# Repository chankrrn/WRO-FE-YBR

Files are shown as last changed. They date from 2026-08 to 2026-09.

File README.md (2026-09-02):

# *YBR-SUNFLOWER 🌻*

<div align="center">

## WRO 2026 Future Engineers

### Official Engineering Documentation

**Yothinburana School — Science–Mathematics English Program**  
**Thailand**

<br>

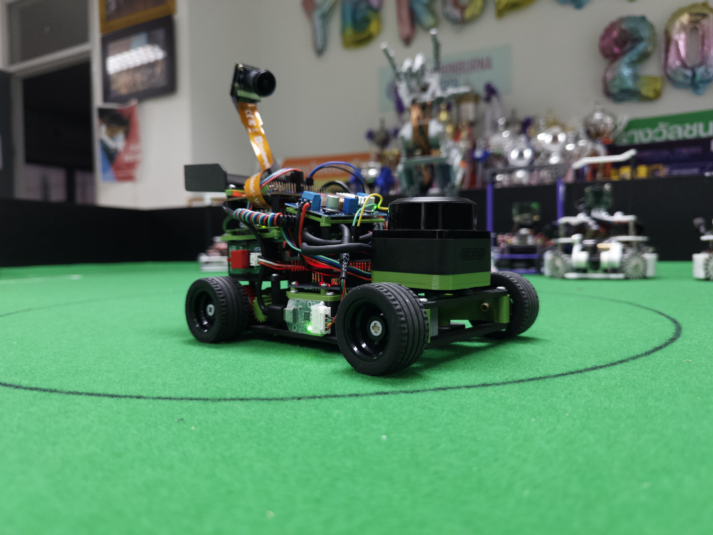
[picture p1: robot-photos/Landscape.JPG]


<br><br>

**Autonomous Self-Driving Vehicle · Mechanical Engineering · Electrical & Sensor Architecture · Localization · Computer Vision · Autonomous Navigation**

</div>

---

## Documentation Quick Links

| Documentation | Purpose |
|---|---|
| [Mechanical Design](mech/mech_README.md) | Chassis, drivetrain, steering, CAD, materials, mechanical calculations, trade-offs and iterations |
| [Electrical & Sensor System](elec/elec_README.md) | Power architecture, controllers, sensors, wiring, calibration, interfaces and reliability |
| [Software Architecture](software/software_README.md) | Localization, path planning, Pure Pursuit, computer vision, sensor fusion, obstacle strategy and parking |
| [Build & Reproduction Guide](BUILD.md) | Complete assembly, wiring, software setup, upload, verification and troubleshooting procedure |
| [Source Code](src/) | Raspberry Pi and Arduino competition software |
| [Schematics](schemes/) | Electrical schematic and physical wiring diagrams |
| [Mechanical Models](mech/models/) | CAD and 3D-printable mechanical parts |
| [Robot Photos](robot-photos/) | Final robot photographs |
| [Videos](video/) | Test and competition demonstration videos |

---

# Contents

1. [Our Team](#1-our-team)
2. [Project Overview](#2-project-overview)
3. [Final Robot](#3-final-robot)
4. [Engineering Development Process](#4-engineering-development-process)
5. [System Architecture](#5-system-architecture)
6. [Mobility and Mechanical Engineering](#6-mobility-and-mechanical-engineering)
7. [Power and Sensor Architecture](#7-power-and-sensor-architecture)
8. [Software Architecture and Autonomous Strategy](#8-software-architecture-and-autonomous-strategy)
9. [Systems Thinking and Major Engineering Decisions](#9-systems-thinking-and-major-engineering-decisions)
10. [Testing, Validation and Failure Analysis](#10-testing-validation-and-failure-analysis)
11. [Build and Reproducibility](#11-build-and-reproducibility)
12. [Repository Structure](#12-repository-structure)
13. [Version History and Development Milestones](#13-version-history-and-development-milestones)
14. [WRO Engineering Documentation Map](#14-wro-engineering-documentation-map)
15. [References and Related Documentation](#15-references-and-related-documentation)

---

# 1. Our Team

## 1.1 Team Members

<div align="center">
  
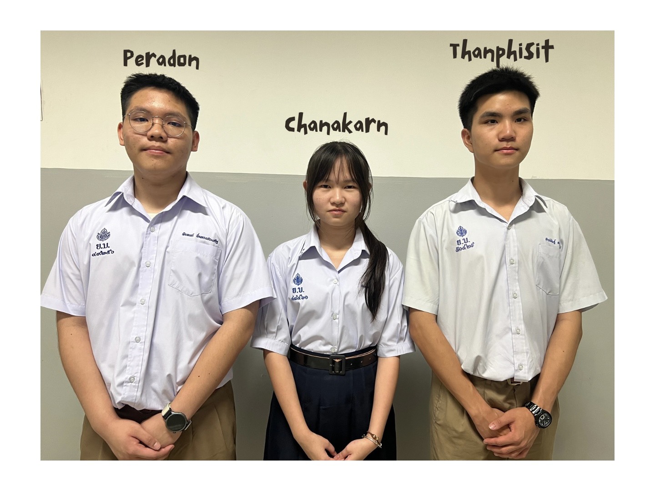
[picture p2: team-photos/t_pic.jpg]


</div>

<br>

We are **YBR-SUNFLOWER**, representing Yothinburana School, Thailand.

| Member | Primary Responsibility | Supporting Responsibilities |
|---|---|---|
| **Peradon Nimsongprasert** | Robot construction and software development | Robot testing, debugging, and performance optimization |
| **Chanakarn Yimsakul** | Documentation and technical writing | Organizing project information, recording development progress, and supporting software development |
| **Thanphisit Sakulvitulthai** | Hardware development and electrical systems | Supporting documentation, hardware testing, and robot assembly |

**Mentor:** Mr. Punnapon Tanasnitikul

---

## 1.2 How We Work as a Team

Our development process integrates mechanical, electrical, and software work throughout the development. A mechanical change can affect steering behavior, while a sensor-placement change can affect localization. Similarly, a power-system change can affect computing reliability, and a software change can reveal mechanical limitations that were not clear during static testing. 

Therefore, subsystem decisions are developed and tested as part of the complete robot rather than independently until the final stage.

Our team divides the work based on each member’s main area of responsibility. Peradon focuses on building the robot and developing the code, Chanakarn is mainly responsible for documentation, and Thanphisit focuses on hardware development while also supporting the documentation. We regularly discuss changes and test the robot together to make sure that mechanical, hardware, and software improvements work well as a complete system.

---

# 2. Project Overview

## 2.1 About YBR-SUNFLOWER

**YBR-SUNFLOWER** is an autonomous self-driving vehicle developed for the **WRO 2026 Future Engineers** competition by a three-member student team from the Science–Mathematics English Program at Yothinburana School, Thailand.

The vehicle combines mechanical design, embedded control, electrical engineering, computer vision, LiDAR localization, orientation sensing and autonomous navigation into one integrated system.

The robot was not developed as a set of independent components. Mechanical, electrical and software decisions were repeatedly changed together as testing revealed limitations in earlier designs.

Our main engineering priorities are:

1. **Precision**
2. **Stability**
3. **Reliability**
4. **Repeatability**
5. **Reproducibility**

We deliberately prioritize predictable autonomous behavior over maximum theoretical speed.

---

## 2.2 Competition Challenge

The WRO Future Engineers competition requires the vehicle to operate fully autonomously on a field whose configuration is not completely known before the round begins.

The competition contains two major driving challenges.

### Open Challenge

The vehicle must autonomously complete three laps while responding to the randomized track configuration and driving direction.

**Performance Video:** [Open Challenge Performance Video](https://youtu.be/PEgQhpqOltk?si=T_KtnxKnviS_btky)

### Obstacle Challenge

The vehicle must:

1. complete three autonomous laps,
2. detect red and green traffic pillars,
3. pass each traffic pillar on the correct side,
4. adapt to randomized obstacle positions,
5. identify the parking situation,
6. and perform the required parallel-parking maneuver.

The starting position, driving direction and field configuration may change between rounds.

For this reason, our final software does not depend on one fixed prerecorded path from one fixed starting point.

**Performance Video:** [Obstacle Challenge Performance Video](https://youtu.be/pB4Do4b9KFg?si=JDbvOoWnJ5U209h_)

> **All the videos including additional testing videos can be found in:** [`video/`](https://github.com/chankrrn/WRO-FE-YBR-SUNFLOWER/tree/17945a607ef416fb5d24ce5c4f617b4a04b09428/video)

---

## 2.3 Competition Constraints That Influenced Our Design

| Constraint | Engineering Response |
|---|---|
| Fully autonomous operation | All sensing, localization, decision-making and actuator control run onboard |
| Randomized field configuration | LiDAR-based localization and field-coordinate navigation |
| Randomized driving direction | Path direction can be selected during initialization |
| Red / green traffic pillars | Camera-based color recognition and obstacle mapping |
| Parallel parking requirement | Distance-based movement and dedicated parking sequence |
| Maximum robot dimensions | Compact stacked mechanical and electrical layout |
| Three-minute run limit | Efficient initialization and autonomous execution |
| One main power switch and one competition start button | Separate SPST main switch and ZX-Switch01 start control |
| Limited onboard power | Single 3S LiPo with separated power branches |
| Limited physical space | Layered chassis and compact sensor placement |

---

## 2.4 Engineering Design Philosophy

A major engineering decision throughout this project was:

> **Precision, stability and repeatability are more important to our robot than maximum speed.**

This principle influenced the complete system. Mechanically, it affected motor selection, drivetrain reduction, Ackermann-style steering, bearing support and chassis rigidity. Electrically, it influenced sensor placement and the decision to separate the Raspberry Pi power path from actuator-related loads.

The same philosophy also influenced software development. Localization, path tracking, steering control and parameter tuning were designed around predictable behavior rather than aggressive speed. The final result is a vehicle intended to perform the same maneuver consistently instead of being optimized only for its fastest possible run.

---

# 3. Final Robot

## 3.1 Robot at a Glance

| Category | Final Configuration |
|---|---|
| Robot type | Four-wheel automotive-style autonomous vehicle |
| Main computer | Raspberry Pi 5 |
| Low-level controller | Arduino UNO R4 Minima |
| Drive motor | CHP-20GP-180 brushed DC geared motor with quadrature encoder |
| Internal motor gearbox | 19:1 reduction |
| External drivetrain | 16-tooth motor gear → 28-tooth differential gear |
| Steering | Servo-driven Ackermann-style steering |
| Steering servo | GEEKSERVO 2 kg 360° servo |
| Distance sensing | RPLiDAR C1 |
| Vision | Raspberry Pi Night Vision Camera |
| Orientation sensing | Gravity BNO055 IMU |
| Drive feedback | Dual-phase motor encoder |
| Pi I/O interface | DFR0566 IO Expansion HAT |
| Motor driver | L298P Motor Shield |
| Main battery | 11.1 V 3S LiPo, 1100 mAh |
| Power architecture | Separate computing and motor/control branches |
| Final dimensions | Approximately **230 × 140 × 130 mm** |
| Final weight without LiPo battery | 768 grams |
| Final weight with LiPo battery | 854 grams |
| Final physical version | Version 3 |

---

## 3.2 Final Robot — Six-View Documentation

The following photographs document the final competition robot from all required directions.

| Front View | Right View | Rear View |
|---|---|---|
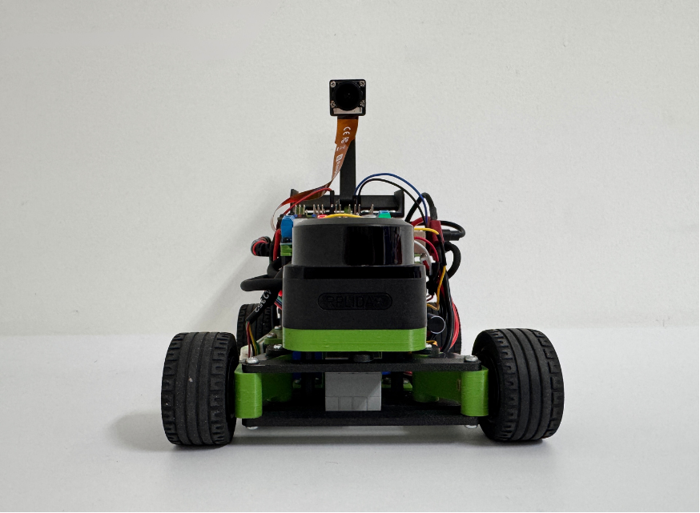
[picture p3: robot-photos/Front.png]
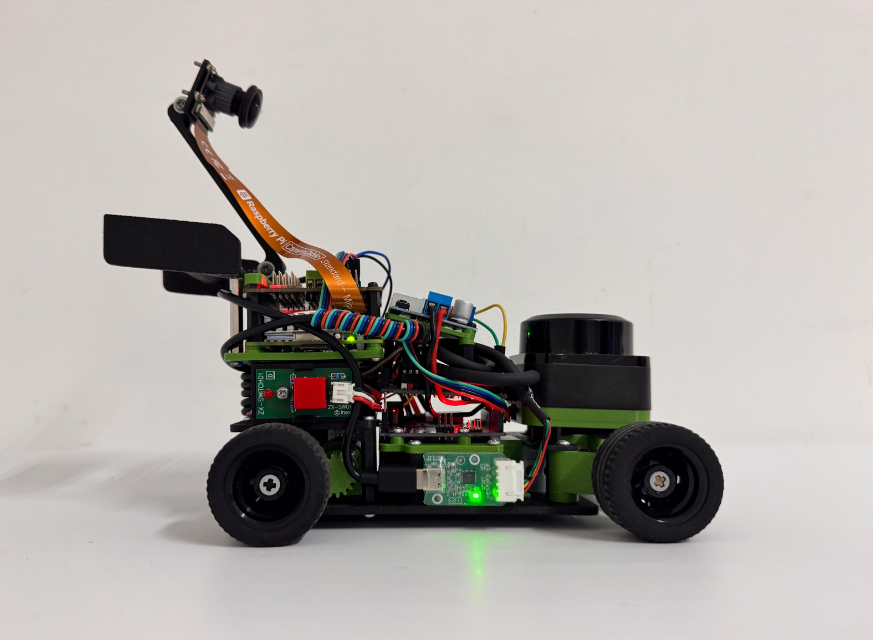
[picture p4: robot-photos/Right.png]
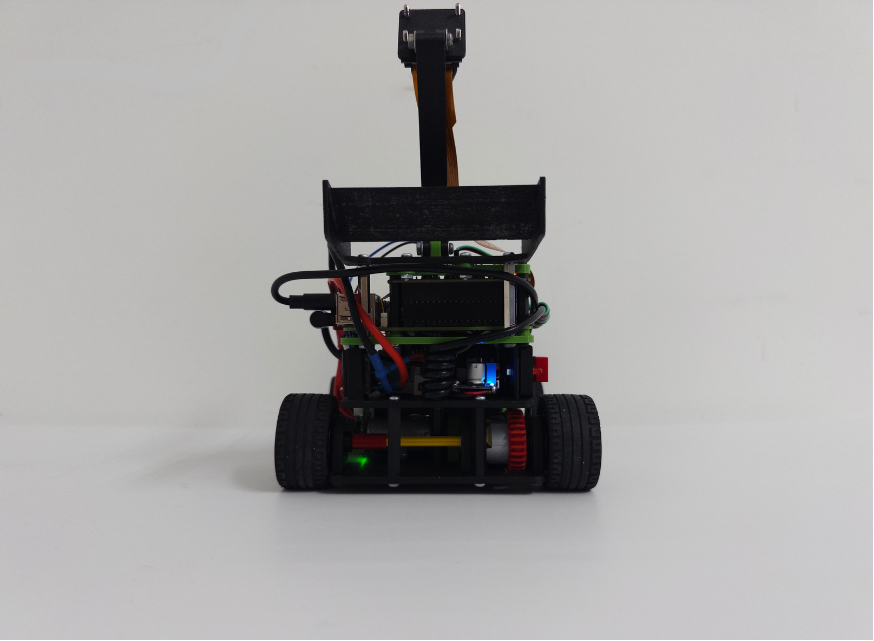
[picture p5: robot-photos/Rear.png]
|  |  |  |

| Left View | Top View | Bottom View |
|---|---|---|
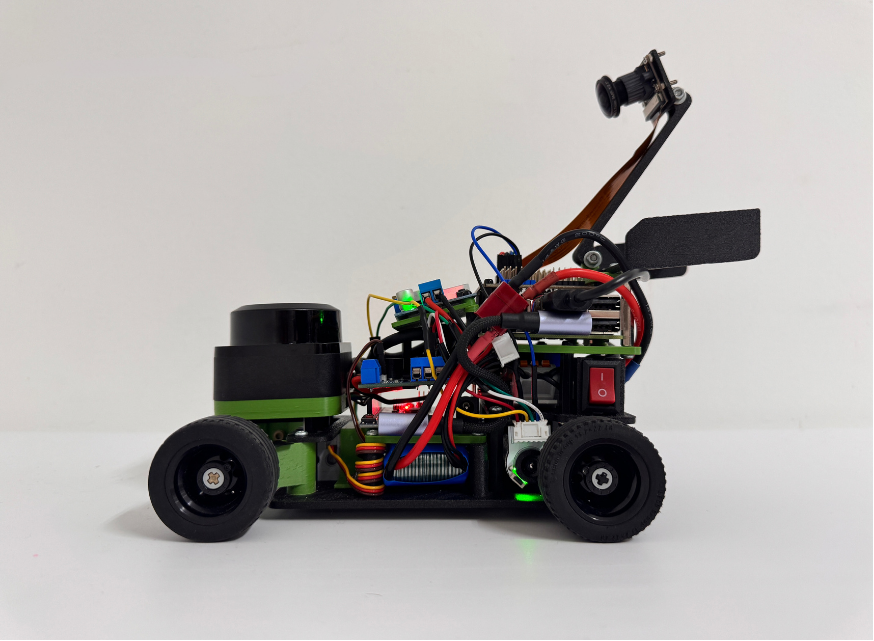
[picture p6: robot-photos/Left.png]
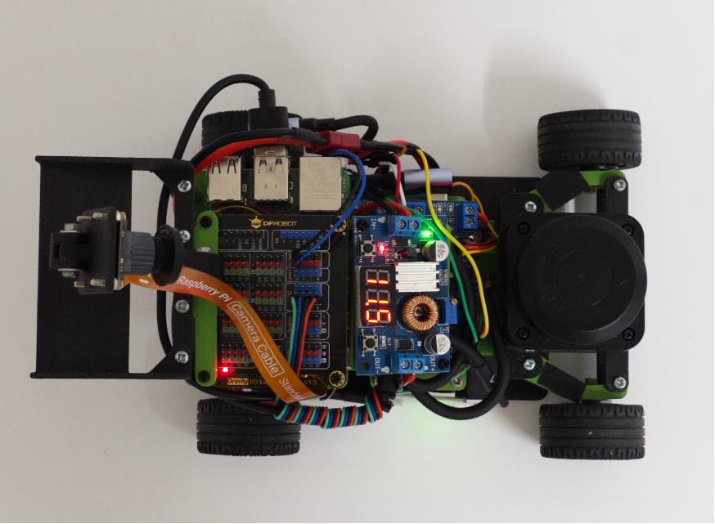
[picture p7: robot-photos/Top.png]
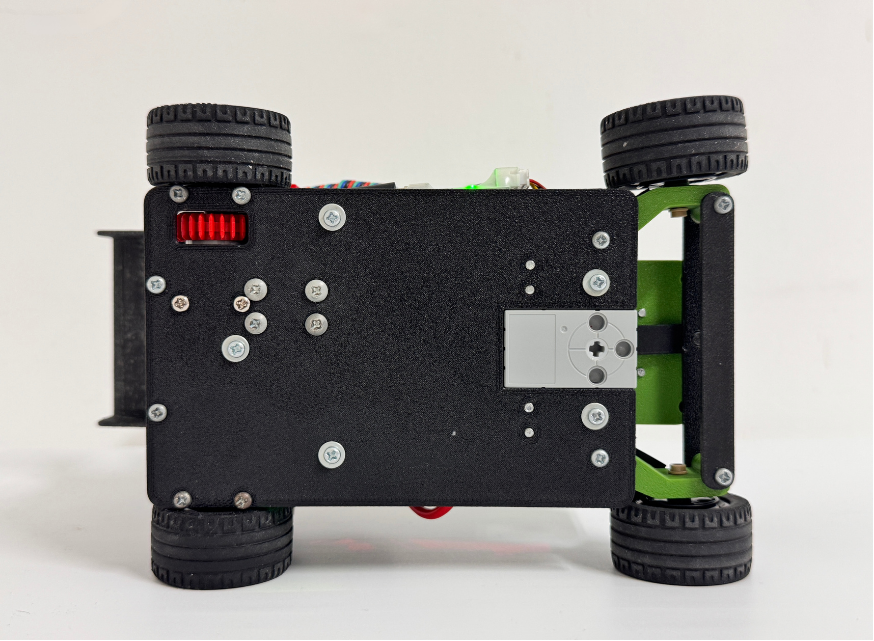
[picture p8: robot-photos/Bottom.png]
|  |  |  |

| Right-Front View | Right-Rear View | Left-Front View | Left-Rear View |
|---|---|---|---|
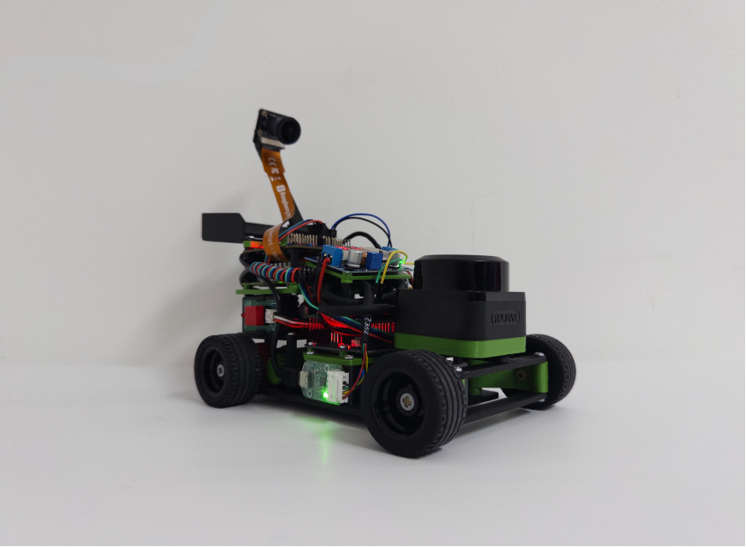
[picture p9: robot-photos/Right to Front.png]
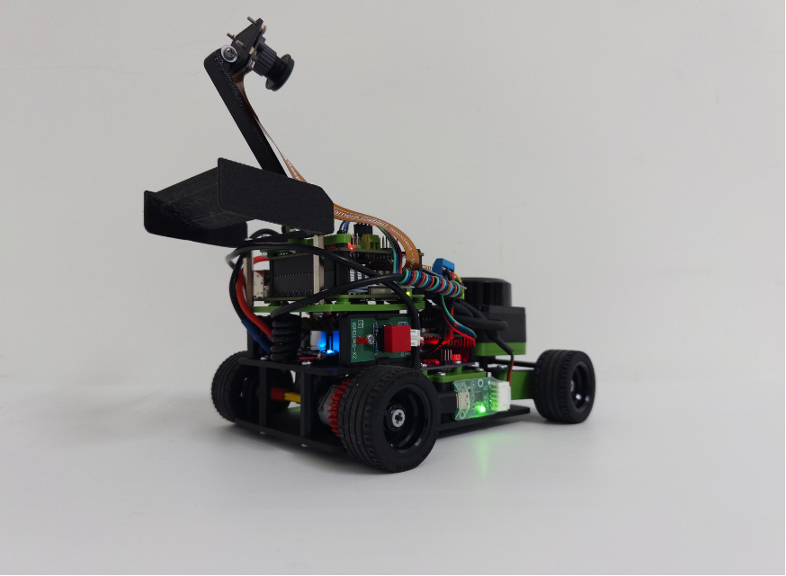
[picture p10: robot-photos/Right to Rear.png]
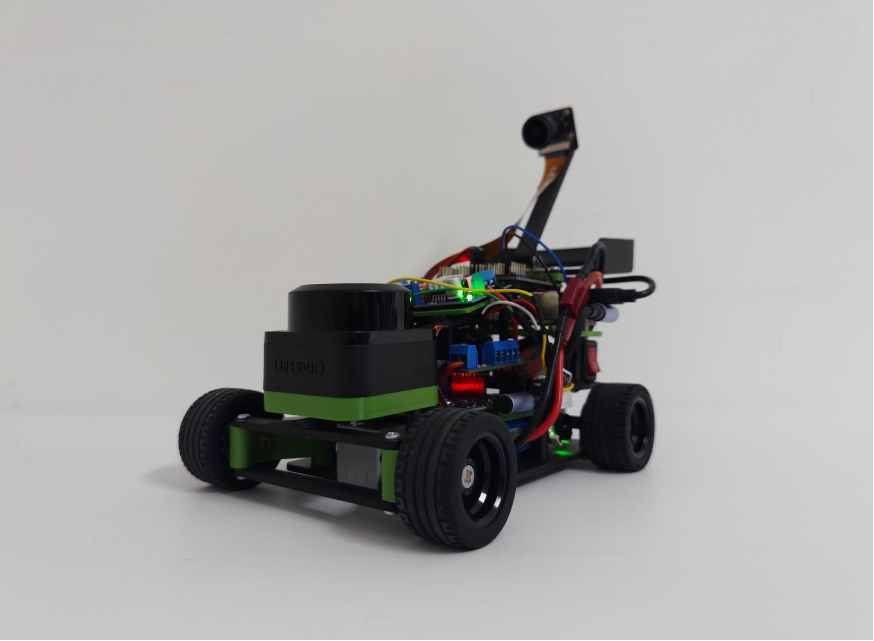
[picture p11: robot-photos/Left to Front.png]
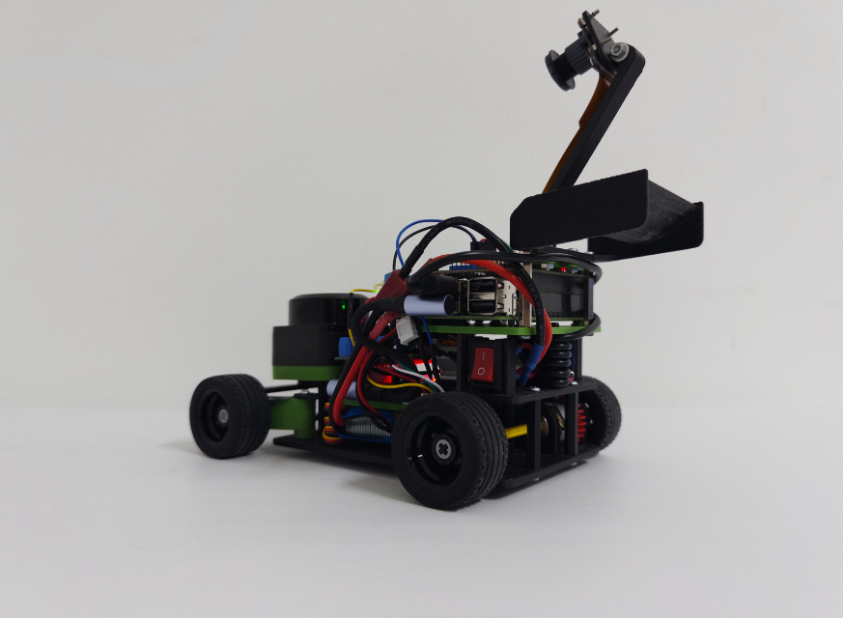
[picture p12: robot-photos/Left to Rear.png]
|  |  |  |  |

## 3.3 Annotated Final Robot Layout

### Overall Component Layout

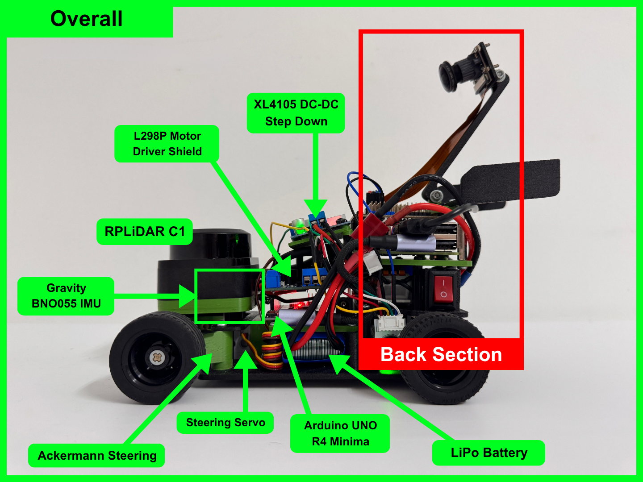
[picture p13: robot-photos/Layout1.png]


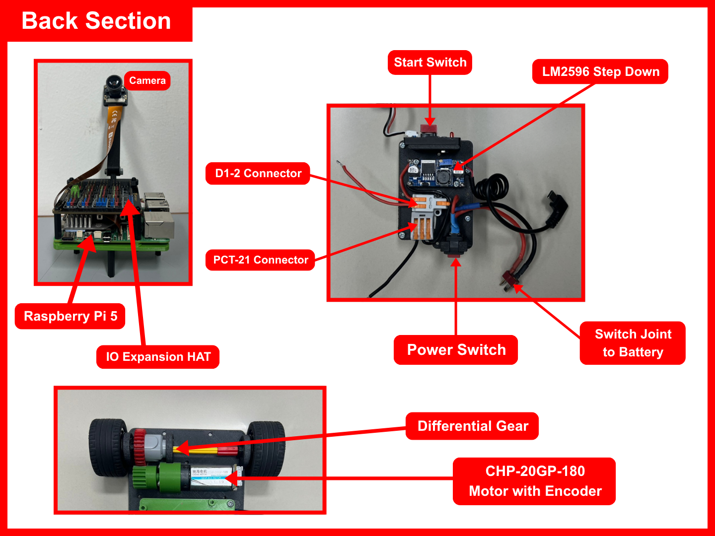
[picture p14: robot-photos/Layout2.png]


<br>

Detailed mechanical and electrical layout documentation is available in:

- [`mech/mech_README.md`](mech/mech_README.md)
- [`elec/elec_README.md`](elec/elec_README.md)

---

# 4. Engineering Development Process

The final robot is the result of multiple design iterations.

Our development followed the repeated engineering cycle:

```text
PLAN
  ↓
BUILD
  ↓
TEST
  ↓
IDENTIFY PROBLEM
  ↓
MODIFY
  ↓
TEST AGAIN
```

We track and document major physical architecture changes using version numbers across each development stage of development.

---

## 4.1 Development Timeline

| Version | Mechanical Development | Electrical / Sensor Development | Software Development | Main Outcome |
|---|---|---|---|---|
| **V1 — Initial Prototype** | Initial printed chassis and 28:28 (1:1) external drivetrain | Initial plan used front ultrasonic sensing + two downward-facing light sensors; a rear ultrasonic sensor was also planned for reverse-distance feedback during parking | Arduino-side control; complete Raspberry Pi autonomous driving not yet implemented | Initial hardware and sensing concept |
| **V2 — LiDAR Prototype** | Same main robot platform with Ackermann steering, bearings and 21:28 external drivetrain | Front ultrasonic sensing was removed; RPLiDAR C1 was introduced; BNO055 was relocated beneath the LiDAR. The two light sensors were still physically attached in the prototype photo but were no longer part of the active sensing strategy | Navigation development and LiDAR-based localization/tuning became the main focus | Functional LiDAR-based prototype without the XL4015 branch |
| **V3 — Final Robot** | Robot was completely rebuilt; final 16:28 drivetrain, improved motor performance, stronger final assembly and several green 3D-printed parts including Ackermann steering-arm components | Core V2 sensing architecture was retained; final wiring was reorganized and an XL4015 DC-DC step-down converter was added to the motor/control-side power architecture | Localization, racing line, Pure Pursuit, obstacle mapping and competition software retained and integrated into the rebuilt platform | Current competition robot and final integrated architecture |

> V1 did not have a complete Raspberry Pi autonomous competition run. We therefore do not claim autonomous performance results for that version. The rear ultrasonic sensor described above was part of the V1 design plan for parking-distance feedback and was not part of the final LiDAR-based architecture.

---

## 4.2 Prototype Comparison

### Version 1

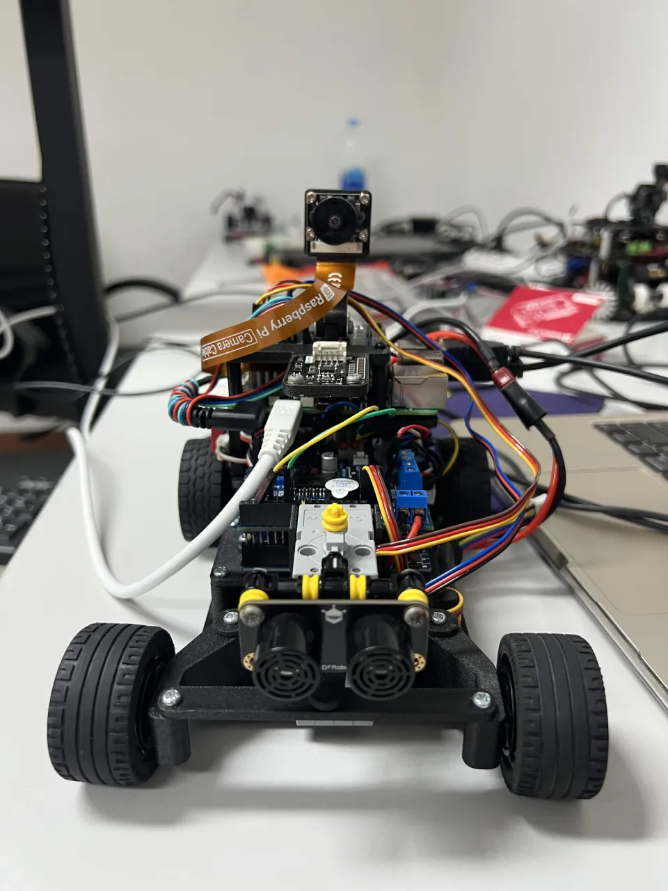
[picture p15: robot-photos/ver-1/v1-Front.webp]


**Main purpose:** establish the initial drivetrain, steering and sensing concept. The original V1 sensing plan used the front ultrasonic sensor for distance measurement together with two downward-facing light sensors. The team also planned to add another ultrasonic sensor at the rear so reverse distance could be observed during the parking maneuver. This concept was replaced before the final autonomous architecture was completed.

### Version 2

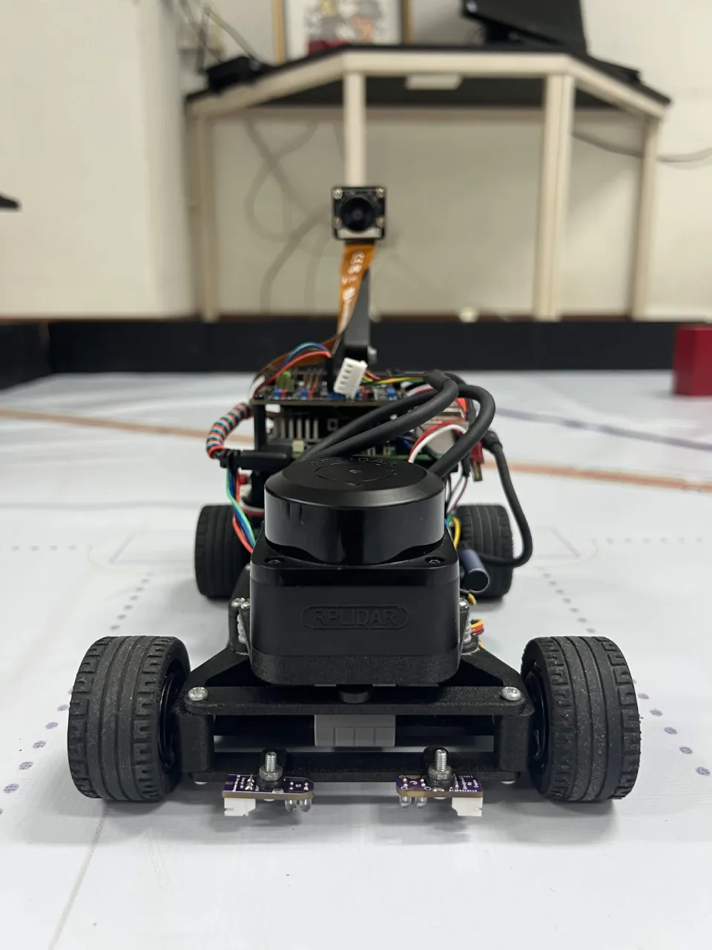
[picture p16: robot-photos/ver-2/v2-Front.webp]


**Main purpose:** integrate LiDAR-based sensing and begin complete autonomous navigation development. The ultrasonic sensor was removed and RPLiDAR C1 became the main environmental-distance sensor. The BNO055 was moved beneath the LiDAR.

> **Photo note:** the two light sensors are still visible on the Version 2 robot in this photograph because the team did not physically remove them from the chassis at that stage. They were no longer used by the active sensing architecture. The ultrasonic sensor, however, had already been removed.

Version 2 did **not** use the final XL4015 motor/control power branch.

### Version 3



**Main purpose:** rebuild the robot into the final competition platform while retaining the core LiDAR + camera + IMU + encoder architecture developed in V2. Version 3 was assembled as a new robot, introduced the final 16:28 drivetrain for improved motor performance, reorganized the final electrical layout, and added the XL4015 DC-DC step-down converter. Several newly printed mechanical parts are green, including parts of the Ackermann steering-arm assembly.

---

## 4.3 Team Engineering Process

### Mechanical Assembly

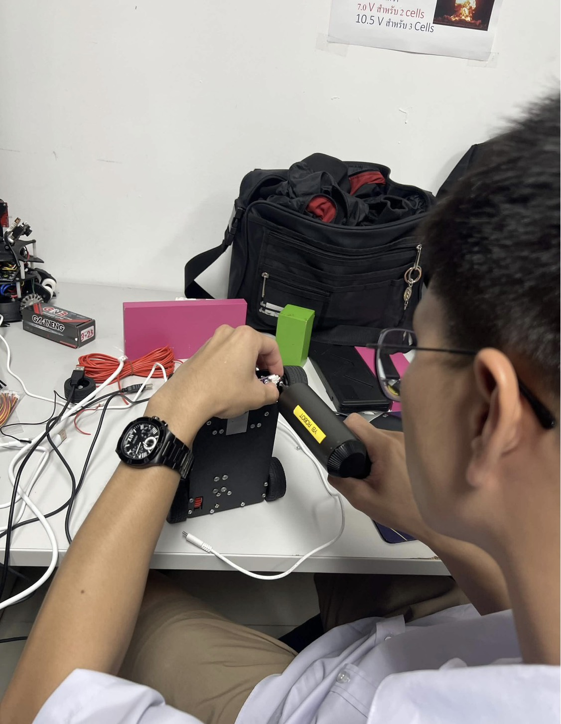
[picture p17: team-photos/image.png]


### Electronics Assembly and Soldering

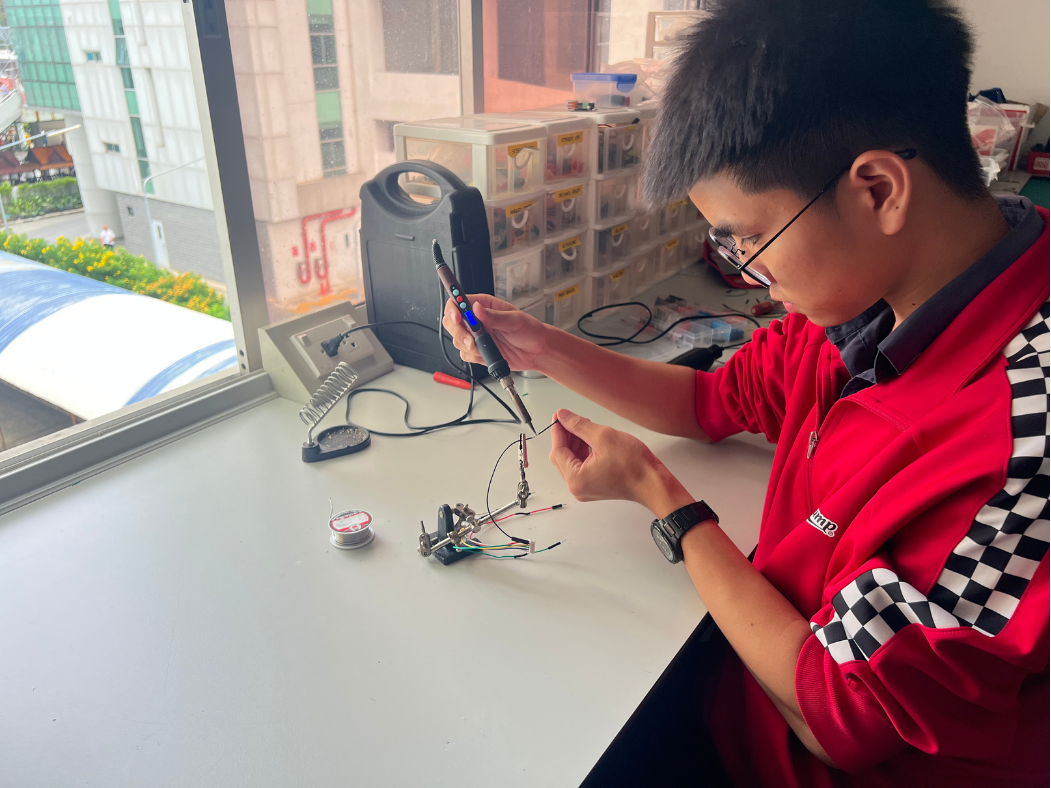
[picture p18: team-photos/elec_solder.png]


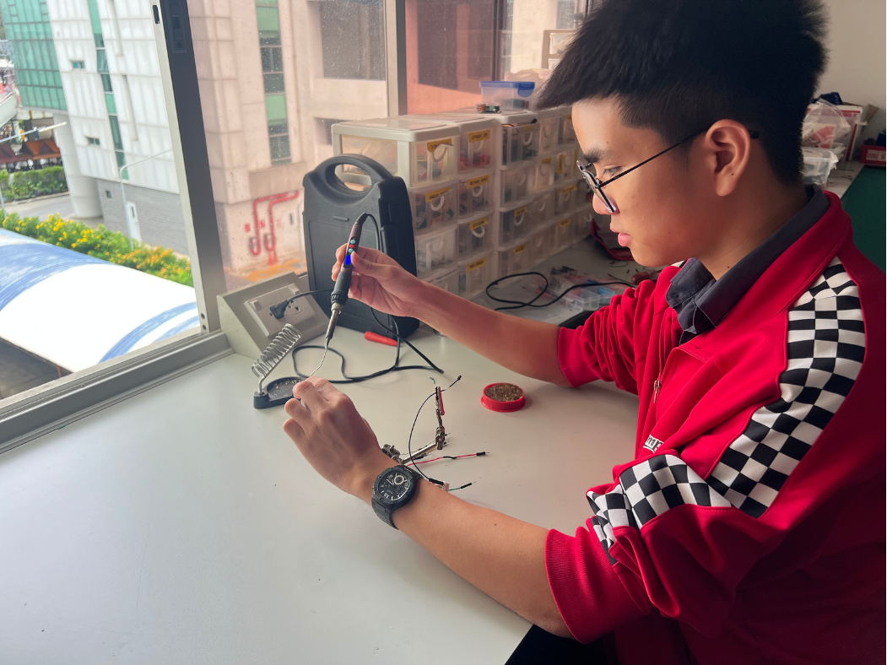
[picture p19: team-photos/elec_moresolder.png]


### Software Development

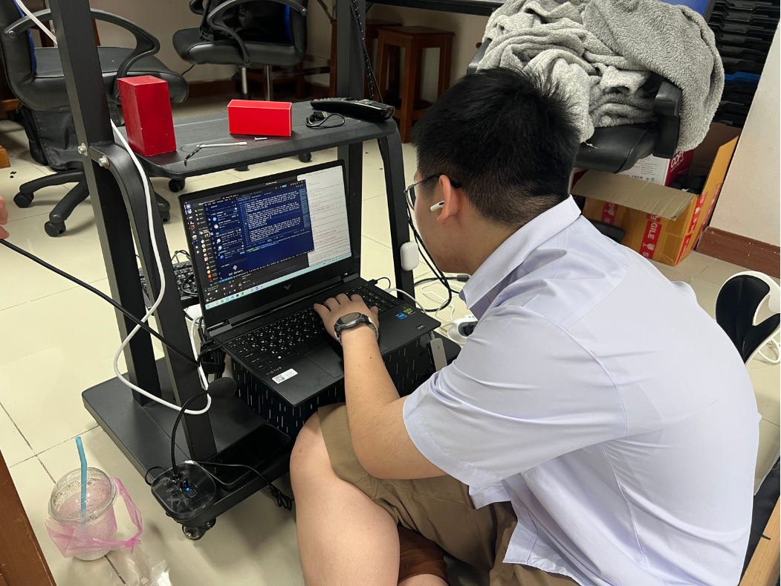
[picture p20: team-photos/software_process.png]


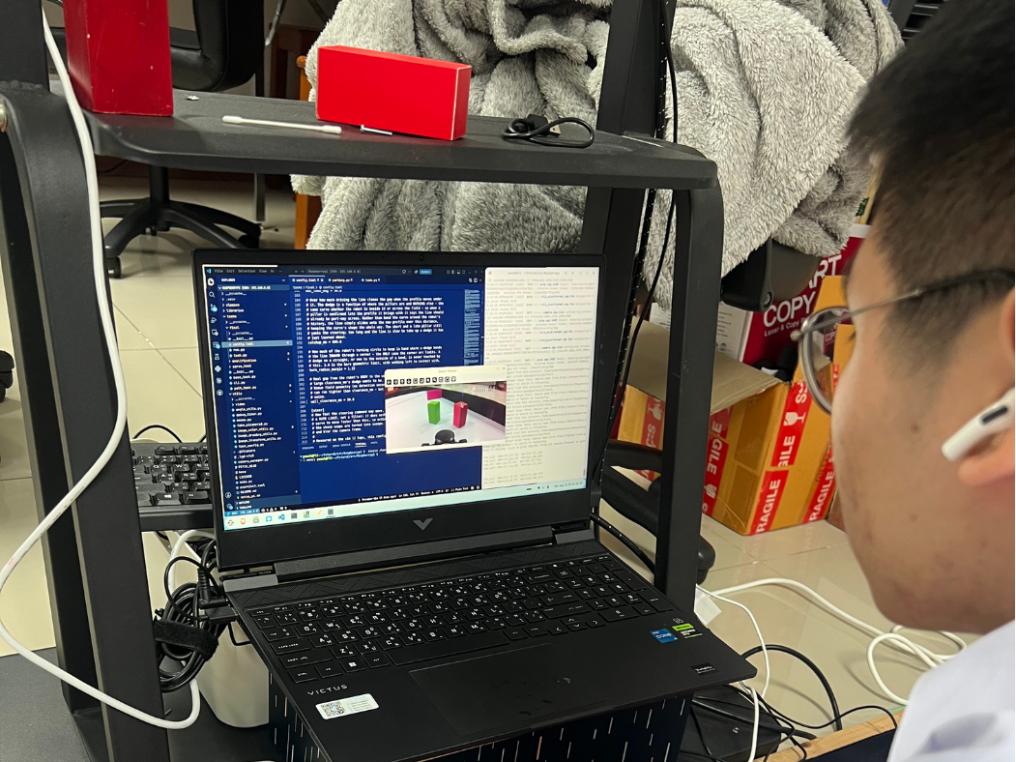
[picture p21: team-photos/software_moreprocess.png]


### Robot Testing

[`video/RunTest_video.md`](https://github.com/chankrrn/WRO-FE-YBR-SUNFLOWER/blob/e39aad0b6cc114cde8bbbf52a57e2f17c71f2b99/video/RunTest_video.md)

---

# 5. System Architecture

## 5.1 High-Level Robot Architecture

The robot is divided into five interacting engineering subsystems:

1. **Mechanical platform**
2. **Power system**
3. **Sensing**
4. **Computing and control**
5. **Autonomous software**

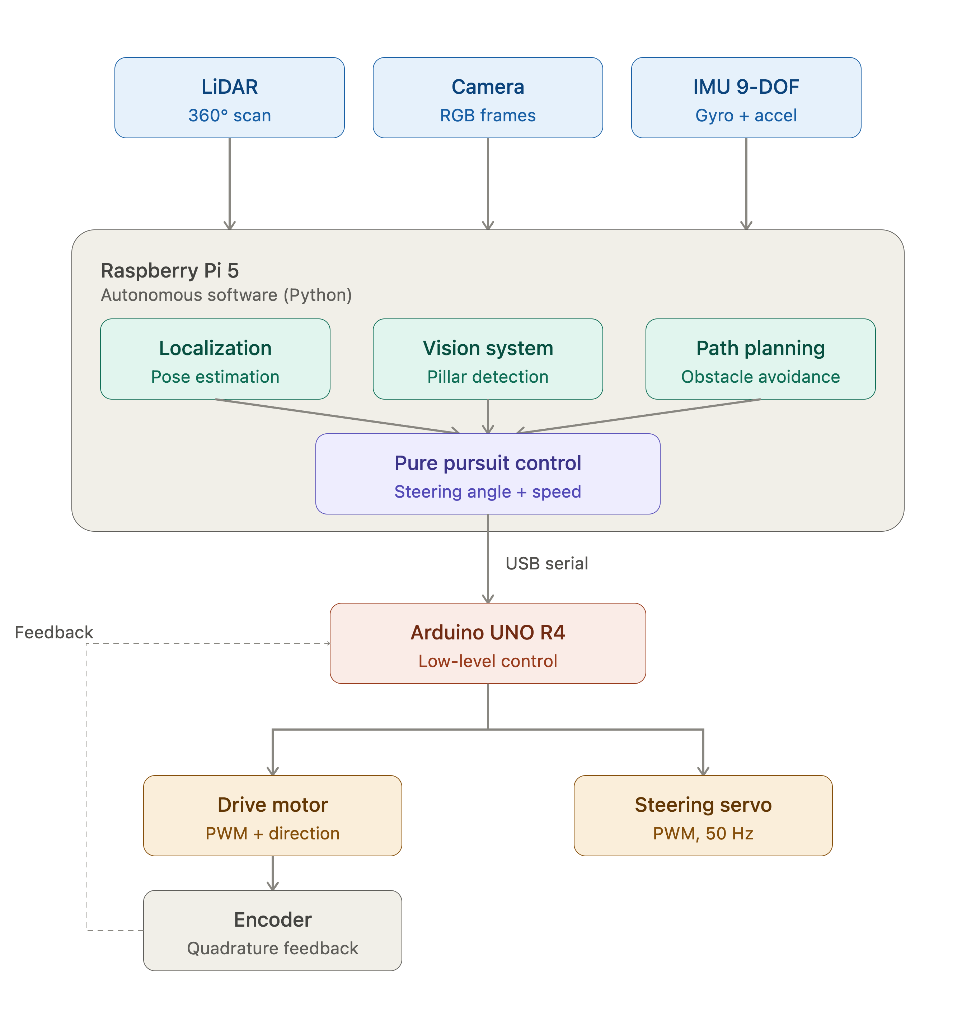
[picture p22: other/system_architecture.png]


The exact interfaces and software modules are documented in the electrical and software documentation.

---

## 5.2 Control Responsibility

### Raspberry Pi 5 — High-Level Control

The Raspberry Pi is responsible for:

- LiDAR processing,
- camera processing,
- IMU reading,
- localization,
- field mapping,
- obstacle detection,
- racing-line generation,
- path tracking,
- autonomous decisions,
- and generation of steering / motor commands.

### Arduino UNO R4 Minima — Low-Level Control

The Arduino is responsible for:

- drive-motor actuation,
- steering-servo actuation,
- quadrature encoder reading,
- start-button input,
- and execution of commands received from the Raspberry Pi.

The two controllers communicate over USB Serial at **115200 baud**.

---

## 5.3 Sensor Roles

| Sensor | Primary Information | Used By |
|---|---|---|
| RPLiDAR C1 | Environment geometry and distance | Localization, clearance and navigation |
| BNO055 IMU | Relative orientation / heading reference | Heading resolution and navigation |
| Camera | Red / green pillar recognition | Obstacle mapping |
| Motor encoder | Drive-motor rotation | Low-level distance feedback |
| Start switch | Competition start command | Run initialization |

No single sensor is expected to solve every perception problem. The camera, LiDAR, IMU and encoder provide different types of information, and the software assigns each of them a specific role according to what that sensor can measure reliably.

---

# 6. Mobility and Mechanical Engineering

The complete mechanical documentation is available in:

## [`mech/mech_README.md`](mech/mech_README.md)

The mechanical system was developed around the same design philosophy used throughout the project:

> **"Predictable controllability is more valuable than maximum speed."**

---

## 6.1 Drivetrain

The final drivetrain combines:

- CHP-20GP-180 motor
- internal 19:1 gearbox
- custom 16-tooth motor drive gear
- 28-tooth LEGO differential gear
- rear differential
- bearing-supported axle
- LEGO-compatible wheels

The final drivetrain uses a CHP-20GP-180 motor with a 19:1 internal gearbox to power a rear differential through a custom 16-tooth motor drive gear meshed with a 28-tooth LEGO differential gear. Ball bearings support the rear axle and reduce direct shaft contact with the printed structure, driving the LEGO-compatible wheels efficiently.

The external drivetrain was developed through several iterations:

```text
V1: 28T → 28T
        1:1

V2: 21T → 28T
     Increased reduction

V3: 16T → 28T
     Final reduction
```

Each step increased the external reduction. This reduced maximum drivetrain speed but increased available torque and improved low-speed controllability, which better matched our autonomous driving and parking requirements.

Detailed torque calculations, motor selection, drivetrain iterations and CAD files are documented in the mechanical README.

---

## 6.2 Steering

The front steering system uses an **Ackermann-style geometry** driven by a GEEKSERVO steering servo.

The final steering assembly includes:

- steering axle,
- left and right steering arms,
- linkage,
- servo bracket,
- upper and lower structural mounts.

The purpose of the geometry is to allow the inner and outer front wheels to follow different turning radii during a corner. This better matches automotive-style motion and reduces unnecessary tire scrub compared with forcing both wheels to use the same steering angle.

---

## 6.3 Mechanical Manufacturing

Most of the custom structural components are manufactured by FDM 3D printing. The team uses both **ABS** and **ABS-GF**, selecting the material according to the mechanical function of each part.

ABS provides greater impact toughness and is suitable for many general structural components, while ABS-GF provides greater stiffness and dimensional stability for parts where deformation is more critical. Detailed material data, part selection and manufacturing information are documented in the mechanical README.

Detailed material selection and 3D models files are documented in the mechanical README.

---

# 7. Power and Sensor Architecture

The complete electrical documentation is available in:

## [`elec/elec_README.md`](elec/elec_README.md)

---

## 7.1 Power Architecture

The robot uses one **11.1 V 3S LiPo battery** as its main power source.

The electrical architecture separates the system into dedicated power branches rather than directly supplying every subsystem from one shared rail.

### Computing Branch

The Raspberry Pi is supplied through an LM2596 step-down converter adjusted to approximately **5.1 V**. This branch is dedicated to the high-level computing system and its connected Pi-side electronics.

### Motor / Control Branch

The actuator and control side uses a separate XL4015-based power path together with the motor-control electronics. On the completed Version 3 robot, the XL4015 output was measured at approximately **11.1 V**, with approximately **11.0 V measured at the downstream motor/control input** under static power-on. Version 2 did not use this XL4015 branch; it was added as part of the Version 3 electrical rebuild.

The separation is intended to reduce direct interaction between rapidly changing actuator loads and the Raspberry Pi power path.

---

## 7.2 Final Sensor Architecture

The original sensing concept changed significantly during development.

### Initial Concept

```text
Camera
+
Ultrasonic Sensors
+
Light Sensor
+
IMU
```

### Final Concept

```text
Camera
+
RPLiDAR C1
+
BNO055 IMU
+
Motor Encoder
```

The V1 sensing plan depended on front ultrasonic distance measurement and two downward-facing light sensors, with an additional rear ultrasonic sensor planned for reverse-distance feedback during parking. In V2, the ultrasonic concept was removed and LiDAR became the main environmental-distance sensor. The light sensors remained physically attached to the V2 prototype for a period, which is why they are visible in some photographs, but they were no longer used by the active sensing architecture. LiDAR provided field geometry over many directions and therefore matched the navigation architecture more effectively.

The camera remains important because LiDAR cannot determine the red or green color of a traffic pillar, while the BNO055 provides orientation information and the motor encoder provides drivetrain feedback.

---

## 7.3 Sensor Placement Iterations

Two important physical sensing problems were identified during development.

### Camera Field of View

**Problem:** the original camera view was too limited for reliable traffic-pillar observation.

**Change:** the camera/lens configuration was changed to provide a wider view.

The purchased OV5647 fish-eye camera reference lists approximately **130° diagonal FOV**, while the current vision software uses approximately **80° horizontal FOV** as its working calibration parameter. These values describe different FOV axes and the camera configuration changed during development, so the software parameter is treated separately from the supplier optical specification.

### LiDAR Orientation

**Problem:** an excessive LiDAR mounting angle distorted the 2D representation of the environment.

**Change:** the LiDAR mounting orientation was corrected closer to parallel with the field.

**Result:** improved 2D scan geometry.

The complete sensor-placement reasoning is documented in the electrical README.

---

# 8. Software Architecture and Autonomous Strategy

The complete software documentation is available in:

## [`software/software_README.md`](software/software_README.md)

Our final software architecture is based on a different question from our original camera-reactive concept.

Instead of asking:

> **"What should I steer away from right now?"**

the final system asks:

> **"Where am I on the field, where should I be, and how should I reach that point?"**

This change led to the final localization-based architecture.

---

## 8.1 Autonomous Navigation Pipeline

The main software pipeline is:

```text
LiDAR + IMU
     │
     v
 Localization
(x, y, heading)
     │
     v
 Racing Line
     │
     v
Target Lookahead Point
     │
     v
 Pure Pursuit
     │
     v
Steering + Speed Command
     │
     v
Arduino
     │
     ├── Drive Motor
     └── Steering Servo
```

---

## 8.2 Localization

The robot uses a **particle filter** to estimate its position on the known WRO field.

The localizer uses:

- LiDAR scan geometry,
- estimated robot motion,
- IMU heading information,
- and the known field map.

The estimated pose contains:

```text
X position
Y position
Heading
Confidence
```

This allows the rest of the navigation system to reason in field coordinates rather than only reacting to the immediate camera image.

---

## 8.3 Racing Line and Pure Pursuit

The robot generates a smooth closed path around the WRO field.

Instead of using a steering PID to continuously react to wall offset, the final navigation system uses **Pure Pursuit**.

Pure Pursuit selects a point ahead of the robot on the target path and calculates the steering required to approach that point.

The principal trade-off is the lookahead distance:

| Lookahead | Advantage | Disadvantage |
|---|---|---|
| Short | Accurate local tracking | Can oscillate at higher speed |
| Long | Smoother and more stable | Can cut corners |

The software therefore adjusts lookahead according to the driving condition.

---

## 8.4 Obstacle Strategy

The camera detects the red and green traffic pillars.

The robot does not switch into a completely separate obstacle-avoidance controller.

Instead:

1. the camera identifies the pillar,
2. estimates its bearing and distance,
3. transforms the detection into field coordinates,
4. stores it in a persistent block map,
5. offsets the racing line around the pillar,
6. and allows the same Pure Pursuit controller to follow the modified path.

This keeps normal path tracking and obstacle handling inside one unified navigation system.

---

## 8.5 Sensor Fusion

Different sensors are trusted for different information.

| Sensor | Trusted For | Not Primarily Used For |
|---|---|---|
| LiDAR | Position, scan geometry, clearance | Pillar color |
| IMU | Relative orientation / heading quadrant | Long-term absolute position |
| Camera | Pillar color, bearing and apparent distance | Wall localization |
| Encoder / motor feedback | Drive movement feedback | Absolute field position |

When sensor information conflicts, the software applies explicit rules rather than assuming every sensor is equally reliable.

Detailed arbitration and failure-handling behavior are documented in the software README.

---

## 8.6 Parking

The final-round software includes a dedicated parking maneuver.

Current high-level parking sequence:

1. position the robot relative to the parking structure,
2. reverse while turning into the parking space,
3. reverse in a straighter trajectory,
4. apply the final steering correction to become parallel with the outer wall,
5. stop.
   
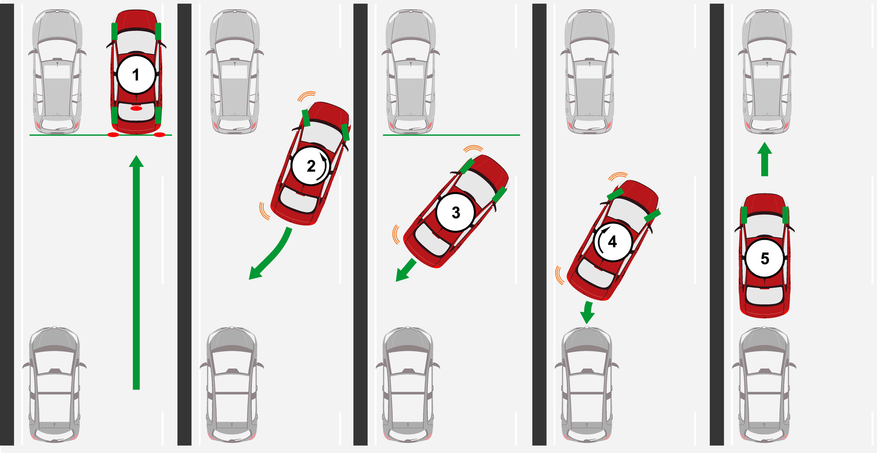
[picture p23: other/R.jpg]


---

# 9. Systems Thinking and Major Engineering Decisions

The robot was developed as one complete system.

The following table summarizes some of the most important decisions.

| Engineering Decision | Alternative / Earlier Design | Reason for Final Choice | Trade-off |
|---|---|---|---|
| 19:1 motor gearbox | Faster 1:5 option | More torque and better low-speed control | Lower maximum speed |
| 16:28 external drivetrain | 28:28 and 21:28 prototypes | Improved low-speed controllability | Additional speed reduction |
| Ackermann-style steering | Simpler steering geometry | Better automotive turning behavior | Increased mechanical complexity |
| LiDAR-based sensing | Ultrasonic + light sensor | Richer environmental information for localization | Higher software complexity |
| Wider-angle camera | Original narrow lens | Larger visual field | Increased image distortion at edges |
| Pi + Arduino architecture | One controller for everything | Separate high-level computing from actuator control | More communication interfaces |
| Separate power branches | One shared low-voltage rail | Reduce motor-related disturbance to Pi supply | Additional converter and wiring |
| Relative IMU reference | Full startup magnetometer calibration | Faster and more practical competition startup | Reduced dependence on absolute magnetic heading |
| Particle-filter localization | Immediate camera-only reaction | Robot can reason about its position on the known field | More computation |
| Pure Pursuit | Reactive steering / competing correction loops | Simple geometric path tracking with clear tuning behavior | Requires a reliable pose |
| Adjustable camera mount | Fixed camera position | Allows angle tuning without redesigning the chassis | More printed parts / joints |
| ABS + ABS-GF | One material for every part | Material selected according to stiffness / toughness requirement | More manufacturing complexity |

Detailed evidence for these decisions is distributed across the mechanical, electrical and software documentation.

---

## 9.1 Subsystem Interaction

### Mechanical → Software

Changing drivetrain reduction changes:

- acceleration,
- maximum speed,
- low-speed controllability,
- steering correction timing,
- and the software speed profile.

### Mechanical → Electrical

Component placement determines:

- cable routing,
- converter position,
- sensor mounting,
- electronics accessibility,
- and weight distribution.

### Electrical → Software

Sensor architecture determines what information the software can use.

Moving from ultrasonic + light sensing to LiDAR changed the software from local reactive sensing toward field localization.

### Software → Mechanical

Software testing revealed real steering behavior that differed from assumed steering geometry.

This required the control model to represent the actual physical steering response rather than only the CAD geometry.

---

# 10. Testing, Validation and Failure Analysis

Testing is used to change the robot design, not only to confirm that the final system works.

---

## 10.1 Software Testing Without the Robot

The software repository includes simulation and test tools that can run important parts of the real navigation software without requiring the complete robot.

Examples include:

```text
test_navigation.py
test_driving.py
test_steering.py
test_color_picker.py
```

These tools allow:

- localization testing,
- random-start trials,
- steering-parameter sweeps,
- steering calibration,
- color-threshold selection,
- and rapid iteration before using limited physical track time.

---

## 10.2 Measured Steering Behavior

Testing identified that the real steering geometry differed from the original assumed value.

The steering calibration process measured approximately:

> **21% more turning than the original assumed full-lock steering value.**

Steering-response testing also measured approximately:

> **0.35 s to reach 63% of the steering response.**

These measurements are important because the real mechanical response affects Pure Pursuit tracking and high-speed stability.

---

## 10.3 Development Problems and Responses

| Problem | Investigation / Observation | Engineering Change | Result |
|---|---|---|---|
| Low drivetrain torque | Robot difficult to control smoothly at low speed | 28:28 → 21:28 → 16:28 external drivetrain | Improved low-speed controllability |
| Narrow camera view | Insufficient visible area | Wider camera/lens configuration | Larger usable view; supplier optical reference and software FOV are documented separately |
| Distorted LiDAR map | LiDAR mounting angle not sufficiently level | Repositioned LiDAR | Improved 2D environment representation |
| Crowded electronics | IMU beside Pi I/O HAT | Relocated IMU under LiDAR | Cleaner physical layout |
| Limited ultrasonic architecture | Needed richer environmental information | Replaced ultrasonic/light-sensor concept with LiDAR | Enabled localization-based navigation |
| Motor-related power changes | Computing and actuator loads interact electrically | Separate power branches | Reduced dependence of Pi supply on actuator branch |
| Steering-model error | Real vehicle turned differently from assumed geometry | Developed steering calibration tools | More accurate control model |
| Sensor disagreement | Sensors provide different types of information | Explicit sensor arbitration | More predictable failure behavior |
| Software exception | Program can terminate unexpectedly | Guaranteed cleanup / motor stop in finalization logic | Robot does not intentionally continue driving after Python failure |

---

# 11. Build and Reproducibility

The complete reproduction procedure is documented in:

# [`BUILD.md`](BUILD.md)

`BUILD.md` is intended to allow others to reproduce the robot using the design files and source code in this repository.

It contains:

1. Reproduction Overview
2. Before You Start
3. Bill of Materials
4. Tools and Manufacturing Equipment
5. 3D Printing and Mechanical Preparation
6. Mechanical Assembly
7. Electrical Assembly and Wiring
8. Electrical Pre-Power Verification
9. Raspberry Pi Software Setup
10. Arduino Setup and Firmware Upload
11. Final Software Configuration
12. Subsystem Verification
13. First Autonomous Run
14. Testing Workflow
15. Troubleshooting
16. Competition Startup Procedure
17. Version Lock and Competition Release
18. Reproducibility Checklist
19. Related Documentation

---

## 11.1 Reproduction Resources

| Resource | Location |
|---|---|
| Mechanical design reasoning | [`mech/mech_README.md`](mech/mech_README.md) |
| Electrical design reasoning | [`elec/elec_README.md`](elec/elec_README.md) |
| Software design reasoning | [`software/software_README.md`](software/software_README.md) |
| Build procedure | [`BUILD.md`](BUILD.md) |
| Source code | [`src/`](src/) |
| 3D files | [`mech/models/`](mech/models/) |
| Electrical schematic | [`schemes/Schematic Diagram.png`](schemes/Schematic%20Diagram.png) |
| Wiring diagram | [`schemes/Wiring Diagram.png`](schemes/Wiring%20Diagram.png) |
| Final robot photographs | [`robot-photos/`](robot-photos/) |

---

## 11.2 First-Run Verification

Before autonomous testing, the build guide verifies:

- power-converter outputs,
- Raspberry Pi startup,
- Arduino connection,
- motor direction,
- steering center,
- encoder feedback,
- LiDAR communication,
- camera operation,
- IMU response,
- start-button behavior,
- and basic straight / turn movement.

This staged verification reduces the chance that several untested subsystems fail simultaneously during the first autonomous run.

---

# 12. Repository Structure

```text
WRO-FE-YBR-SUNFLOWER/
│
├── README.md
├── BUILD.md
├── LICENSE.md
├── .gitignore
│
├── mech/
│   ├── mech_README.md
│   └── models/
│       ├── STL files
│       └── PNG files
│
├── elec/
│   └── elec_README.md
│
├── software/
│   └── software_README.md
│
├── src/
│   ├── Arduino/
│   │   ├── Main.ino
│   │   └── libraries/
│   │
│   └── Raspberrypi/
│       ├── main.py
│       ├── tasks/
│       ├── classes/
│       ├── utils/
│       ├── liraries
│       ├── test_*.py
│       ├── pyproject.toml
│       └── uv.lock
│
├── schemes/
│   ├── README.md
│   ├── Schematic Diagram.png
│   └── Wiring Diagram.png
│
├── robot-photos/
│   ├── front.jpg
│   ├── rear.jpg
│   ├── left.jpg
│   ├── right.jpg
│   ├── top.jpg
|   ├── bottom.jpg
|   ├── ver-0/
|   ├── ver-1/
│   └── ver-2/
│
├── team-photos/
|   ├── t-pic.jpg
│   └── PNG files
│
├── video/
|   ├── RunTest_video.md
│   └── final_video.md
│
└──  other/
    ├── PNG files
    └── JPG files

```

---

# 13. Version History and Development Milestones

The Git history is part of the engineering documentation because it shows that the robot was developed iteratively rather than uploaded only as a final code dump.

## 13.1 Physical Versions

| Version | Major Change | Status |
|---|---|---|
| V1 | Initial chassis, 28:28 external drivetrain; front ultrasonic + light-sensor sensing plan, with rear ultrasonic planned for parking-distance feedback | Archived prototype |
| V2 | Ackermann steering, bearings, 21:28 drivetrain and LiDAR architecture; ultrasonic removed; light sensors still physically present in some photos but no longer active; no XL4015 branch | Functional prototype |
| V3 | Completely rebuilt robot, 16:28 drivetrain, improved motor performance, green reprinted mechanical parts, final electrical layout and added XL4015 motor/control power branch | Current robot |

---

# 14. WRO Engineering Documentation Map

This repository separates detailed engineering information by subsystem so that each part of the robot can be evaluated and reproduced clearly.

| WRO Engineering Area | Primary Evidence | Additional Evidence |
|---|---|---|
| **Mobility and Mechanical Design** | [`mech/mech_README.md`](mech/mech_README.md) | CAD, drivetrain iterations, material selection, robot photos |
| **Power and Sensor Architecture** | [`elec/elec_README.md`](elec/elec_README.md) | Schematics, wiring, power budget, sensor placement and calibration |
| **Software Architecture and Obstacle Strategy** | [`software/software_README.md`](software/software_README.md) | Source code, localization, Pure Pursuit, object detection, parking and tests |
| **Systems Thinking and Engineering Decisions** | [Section 9](#9-systems-thinking-and-major-engineering-decisions) | Prototype history, trade-offs, failure analysis and subsystem interactions |
| **Reproducibility and GitHub Quality** | [`BUILD.md`](BUILD.md) | CAD, code, wiring, repository structure, test workflow, Git history and release notes |

---

## 14.1 Evidence Philosophy

We distinguish between:

- **manufacturer specifications,**
- **calculated values,**
- **software configuration values,**
- **observed behavior,**
- and **team-measured test results.**

Quantitative performance values are only reported as measurements when the team actually recorded them.

This prevents unmeasured estimates from being presented as experimental results.

---

# 15. References and Related Documentation

## Internal Documentation

- [`mech/mech_README.md`](mech/mech_README.md) — Mechanical engineering
- [`elec/elec_README.md`](elec/elec_README.md) — Electrical and sensing
- [`software/software_README.md`](software/software_README.md) — Software and autonomy
- [`BUILD.md`](BUILD.md) — Complete reproduction guide
- [`schemes/`](schemes/) — Electrical diagrams
- [`src/`](src/) — Competition source code

## External References

> **[Official WRO 2026 Future Engineers rules link](https://gammaco.co.th/wro/wp-content/uploads/2026/03/TH-WRO-2026-Future-Engineers-General-Rules.pdf)**

Component datasheets and manufacturer references are maintained in the subsystem documentation where they are directly relevant to the engineering decisions.

---

# Final Summary

YBR-SUNFLOWER is the result of an iterative engineering process that connects mechanical design, electrical architecture, sensing and autonomous software.

The project evolved from an initial V1 concept based on ultrasonic and light sensing, through a V2 LiDAR prototype, into a completely rebuilt Version 3 competition robot. Version 3 retained the core V2 sensing architecture but added the final 16:28 drivetrain, improved motor performance, reorganized electrical packaging, several green reprinted mechanical parts, and the XL4015 motor/control power branch.

The final localization-based autonomous vehicle uses:

- a torque-focused drivetrain,
- Ackermann-style steering,
- LiDAR localization,
- relative IMU heading,
- camera-based traffic-pillar detection,
- Pure Pursuit path tracking,
- separate high-level and low-level controllers,
- and structured power distribution.

The repository documents not only the final robot, but also the decisions, problems, trade-offs, testing and iterations that produced it.

Our goal is that others should be able to understand **what we built, why we built it this way, how it works, how it was tested, and how to reproduce it** from the documentation contained here.

---

<div align="center">

### YBR-SUNFLOWER

**WRO 2026 Future Engineers**

Yothinburana School · Thailand

**Mechanical · Electrical · Software · Autonomous Systems**

</div>

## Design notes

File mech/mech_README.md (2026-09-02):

# Mechanical Design & Mobility System

This document describes the complete mechanical development of the **YBR-SUNFLOWER WRO 2026 Future Engineers robot**, including the drivetrain, steering system, chassis, structural components, mechanical calculations, material selection, manufacturing process, prototype iterations, testing, trade-offs, and final engineering decisions.

The purpose of this document is not only to show the final mechanical design. It explains why the main components were selected, how torque and speed influenced the drivetrain, why the steering and transmission use their current architecture, and how the robot developed from a previous-generation reference platform into the final Version 3 vehicle.

It also documents the mechanical problems discovered during development, the changes made after testing, the trade-offs accepted by the team, and the information required to reproduce the final mechanical platform.

---

# Contents

1. [Mechanical Engineering Overview](#1-mechanical-engineering-overview)
2. [Mechanical Design Requirements and Philosophy](#2-mechanical-design-requirements-and-philosophy)
3. [Mechanical Development Process — V0 to V3](#3-mechanical-development-process--v0-to-v3)
4. [Final Mechanical Architecture](#4-final-mechanical-architecture)
5. [Drivetrain Engineering](#5-drivetrain-engineering)
6. [Steering System](#6-steering-system)
7. [Structural Design and Final 3D Components](#7-structural-design-and-final-3d-components)
8. [Mechanical Sensor and Electronics Integration](#8-mechanical-sensor-and-electronics-integration)
9. [Manufacturing and Material Selection](#9-manufacturing-and-material-selection)
10. [Mechanical Testing and Iteration](#10-mechanical-testing-and-iteration)
11. [Mechanical Trade-offs and Engineering Decisions](#11-mechanical-trade-offs-and-engineering-decisions)
12. [Mechanical Risks and Failure Modes](#12-mechanical-risks-and-failure-modes)
13. [CAD Files and Reproducibility](#13-cad-files-and-reproducibility)
14. [Final Mechanical Configuration](#14-final-mechanical-configuration)

---

# 1. Mechanical Engineering Overview

The YBR-SUNFLOWER robot uses a four-wheel automotive-style architecture with rear-wheel drive and front-wheel steering.

The final mobility system uses one rear drive motor connected to a rear differential through a custom external gear reduction. The two rear wheels provide propulsion, while the two front wheels are controlled by a servo-driven Ackermann-style steering mechanism. The drivetrain shafts are supported by bearings to improve alignment and reduce friction against printed components.

The mechanical structure is built mainly from modular FDM 3D-printed parts. These include the main chassis, electronics layers, camera structure, LiDAR / IMU mount, drivetrain mounts and steering components. This modular architecture allows individual parts to be redesigned or replaced without rebuilding the complete robot.

Our mechanical design was developed around one central principle:

> **Precision, controllability, stability and repeatability are more important to our application than maximum theoretical speed.**

This principle influenced the motor, drivetrain reduction, wheel choice, steering geometry, bearing system, chassis structure and material selection.

---

## 1.1 Mechanical System at a Glance

| Category | Final Configuration |
|---|---|
| Vehicle layout | Four-wheel automotive-style vehicle |
| Drive architecture | Rear-wheel drive |
| Drive motor | CHP-20GP-180 DC geared motor |
| Internal gearbox | 19:1 reduction |
| External drive gear | Custom 16-tooth 3D-printed gear |
| Differential gear | LEGO Technic 28-tooth differential |
| External reduction | 28 / 16 = 1.75:1 |
| Steering | Ackermann-style front steering |
| Steering actuator | GEEKSERVO 2 kg 360° servo |
| Wheels | LEGO Tire 43.2 × 22 ZR |
| Rear axle support | Ball bearings + custom axle sleeves |
| Main structural materials | ABS and ABS-GF |
| Manufacturing method | FDM 3D printing |
| Main printer | Bambu Lab H2D |

---

## 1.2 Criterion 1 Evidence Map

| Level 6 Requirement | Evidence in This Document |
|---|---|
| Torque and speed reasoning | Section 5 |
| Drivetrain selection | Sections 5.1–5.7 |
| Steering mechanism | Section 6 |
| Component-selection reasoning | Sections 5, 6 and 9 |
| Structural stability | Section 7 |
| Design trade-offs | Section 11 |
| Testing and iteration | Sections 3 and 10 |
| Mechanical failure analysis | Section 12 |
| Reproducible mechanical design | Section 13 |

---

# 2. Mechanical Design Requirements and Philosophy

## 2.1 Mechanical Requirements

The mechanical platform must accelerate smoothly from a stop, maintain a controllable driving speed and respond consistently to repeated steering corrections. It also needs to negotiate the WRO corners, pass traffic pillars with sufficient control and perform low-speed parking maneuvers.

At the same time, the chassis must support the complete computing, power and sensing system without allowing excessive sensor movement. The vehicle must remain compact enough for the competition field while still providing enough structural space for the Raspberry Pi, Arduino, converters, battery, camera, LiDAR and IMU.

These requirements mean that mechanical performance cannot be evaluated only by maximum speed. Low-speed control, steering repeatability, rigidity and component integration are equally important.

---

## 2.2 Main Mechanical Constraints

| Constraint | Effect on Mechanical Design |
|---|---|
| Limited robot footprint | Compact layered chassis |
| Parking requires low-speed precision | Torque prioritized over maximum speed |
| Repeated cornering | Ackermann-style steering and differential |
| Heavy onboard electronics | Rigid multi-layer structure |
| LiDAR requires stable mounting | Dedicated upper sensor support |
| Camera requires tuning | Adjustable camera mechanism |
| 3D-printed drivetrain parts | Material and bearing selection become important |
| Need for rapid redesign | Modular printed components |

---

## 2.3 Design Philosophy

Our initial development showed that the fastest drivetrain is not automatically the most useful drivetrain for an autonomous WRO vehicle.

The robot repeatedly needs to enter corners, make steering corrections, pass close to obstacles and perform precise low-speed movement. If the drivetrain produces high speed but cannot be controlled consistently, the software has less time and less mechanical authority to correct the vehicle.

This led to our main mechanical philosophy:

> **We deliberately accept lower maximum speed when the change increases torque, low-speed controllability, stability and repeatability.**

The drivetrain progression demonstrates this philosophy clearly:

```text
28:28
  ↓
21:28
  ↓
16:28
```

Each step increased the external gear reduction. The theoretical maximum wheel speed decreased, but the available torque multiplication and low-speed controllability increased.

---

# 3. Mechanical Development Process — V0 to V3

The final robot was not created in one design step. Its mechanical architecture developed through a sequence of reference study, prototyping, physical testing and redesign.

```text
V0 — Reference Blueprint
        ↓
V1 — First Team Prototype
        ↓
V2 — Functional Prototype
        ↓
V3 — Final Competition Robot
```

---

## 3.1 V0 — Reference Blueprint / Previous-Generation Robot

> **Important:** V0 was not built as part of the current YBR-SUNFLOWER 2026 development cycle.

V0 refers to the **white robot developed by our senior team in the previous season**. Before starting the current robot, we studied this platform as a mechanical reference.

We did not treat V0 as a design that should simply be copied. Instead, it acted as a starting blueprint that helped us identify mechanical requirements, limitations and questions that should be investigated in the new platform.

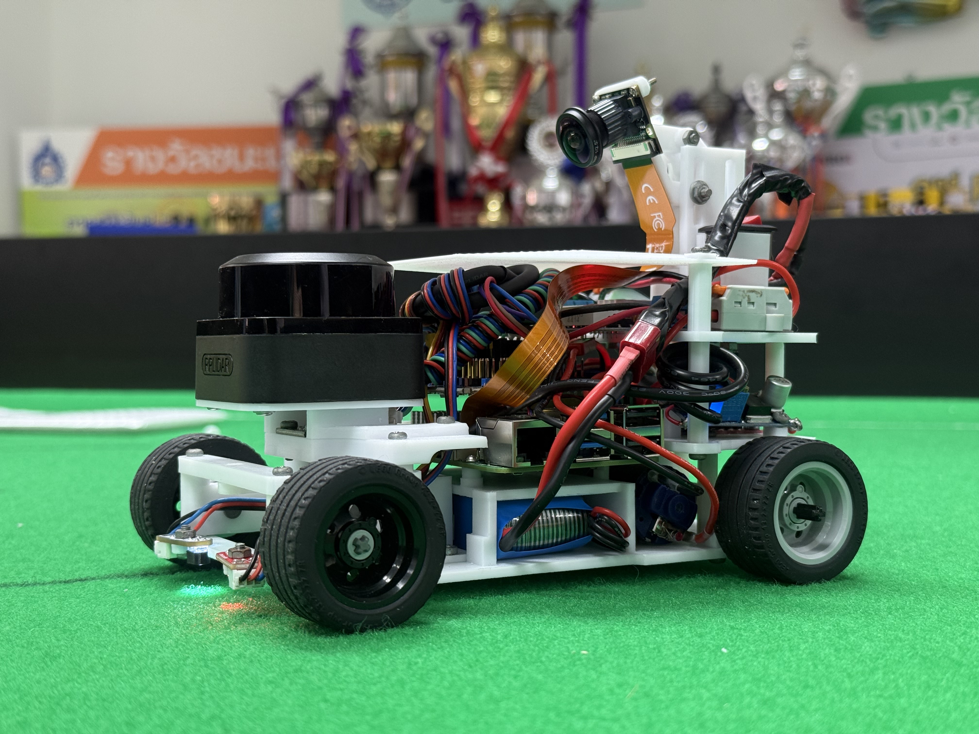
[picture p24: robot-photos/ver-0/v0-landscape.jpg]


> **Figure — V0 reference robot from the previous season. This vehicle was studied as a mechanical reference before the current team began developing V1.**

---

### 3.1.1 Lessons Taken from V0

One of the most important lessons from the previous-generation robot was the relationship between **speed and controllability**.

The previous approach focused more strongly on speed and used conventional DC motors without the encoder configuration selected for our current platform. From this reference design, we recognized that high speed alone does not guarantee consistent autonomous performance. A robot can move quickly but still struggle with very low-speed motion, precise positioning and parking.

The reference platform also helped us recognize that the mechanical drivetrain must support the requirements of the autonomous control system. These observations influenced our decision to investigate a geared motor with integrated encoder feedback for the new robot.

---

### 3.1.2 How V0 Influenced V1

V0 gave us several engineering questions that became the starting point for V1.

We wanted to determine how to obtain more controllable low-speed movement and how to balance drivetrain speed with torque. We also needed a steering mechanism designed specifically for the new chassis, a structure that could be modified rapidly during development and enough space to support the sensors and electronics required by the new navigation strategy.

These questions guided the design of the first current-generation prototype.

---

## 3.2 V1 — Initial Mechanical Prototype

<table align="center">
  <tr>
    <td align="center">
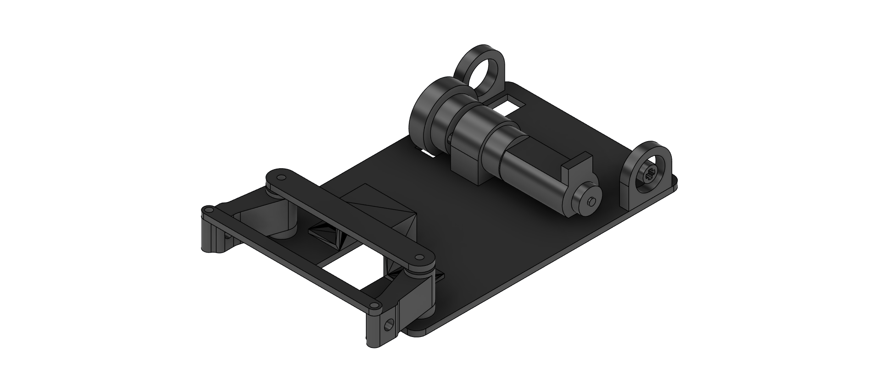
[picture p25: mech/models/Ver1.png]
      
    </td>
  </tr>
</table>

V1 was the first mechanical prototype developed for the current robot. Its purpose was not to create a complete competition-ready vehicle immediately, but to test whether the basic drivetrain, steering and printed-chassis concept could work physically.

The prototype used a 3D-printed base and a **28:28 external gear configuration**, creating a **1:1 external ratio**.

```text
Motor Gear: 28T
      ↓
Differential Gear: 28T

External Ratio = 1:1
```

---

### 3.2.1 Goal of V1

The main engineering question for V1 was:

> **Can the basic motor, drivetrain, chassis and steering concept physically move the vehicle as expected?**

At this stage, simplicity was more important than optimization. The team first needed to establish a working baseline before changing the drivetrain ratio or building a more complex structure.

---

### 3.2.2 Problem Identified

Testing showed that the 1:1 external drivetrain did not provide the amount of low-speed torque and controllability that we wanted.

The robot could move, but acceleration from rest was less controllable, slow movement was difficult and repeated steering corrections were harder to perform consistently. This behavior did not match our precision-focused design philosophy.

The drivetrain result therefore became one of the main reasons for changing the external gear ratio in V2.

---

## 3.3 V2 — Functional Mechanical Prototype

<table align="center">
  <tr>
    <td align="center">
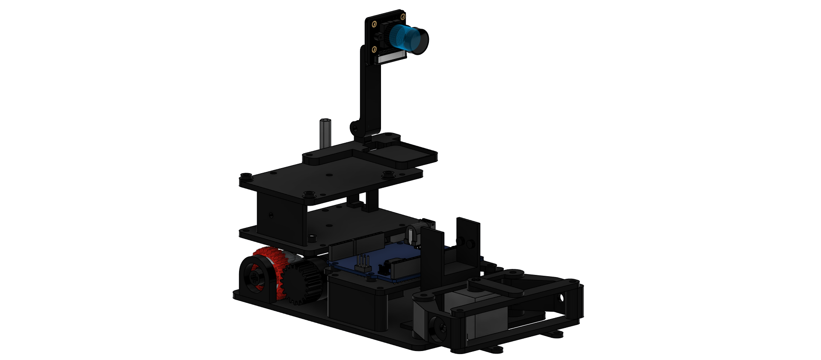
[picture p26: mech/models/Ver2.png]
      
    </td>
  </tr>
</table>

V2 developed the V1 concept into a much more complete mechanical platform.

The motor drive gear was reduced from 28 teeth to **21 teeth**, increasing the external reduction. An Ackermann-style steering architecture was introduced, rear drivetrain bearings were added and the chassis was expanded to support more of the final electronic system.

At this point the robot became mechanically usable, although several areas still required further improvement.

---

### 3.3.1 Drivetrain Change

The drivetrain changed from:

```text
V1

28T → 28T

1:1
```

to:

```text
V2

21T → 28T

28 / 21 ≈ 1.33:1 reduction
```

The smaller driver gear increased the external reduction. The theoretical wheel speed decreased, while the theoretical output torque increased.

In practice, the change also produced better low-speed behavior and made the drivetrain more suitable for repeated autonomous steering corrections.

---

### 3.3.2 Steering Development

V2 introduced the Ackermann-style steering architecture that became the basis of the final steering system.

During a turn, the inner front wheel and outer front wheel follow different path radii. The steering mechanism was therefore designed so that the wheels do not need to use exactly the same steering angle.

This geometry reduces unnecessary tire scrub and better matches the automotive-style motion of the vehicle.

---

### 3.3.3 Bearing Development

V2 also introduced bearings to support the rear drivetrain shaft.

Without bearings, the rotating axle would interact directly with printed structural surfaces. The bearing system separates the rotating shaft from the fixed printed structure and improves alignment, smoothness and rigidity.

This also improves drivetrain consistency over repeated use because the axle is less dependent on sliding directly against the 3D-printed material.

---

## 3.4 V3 — Final Competition Robot

<table align="center">
  <tr>
    <td align="center">
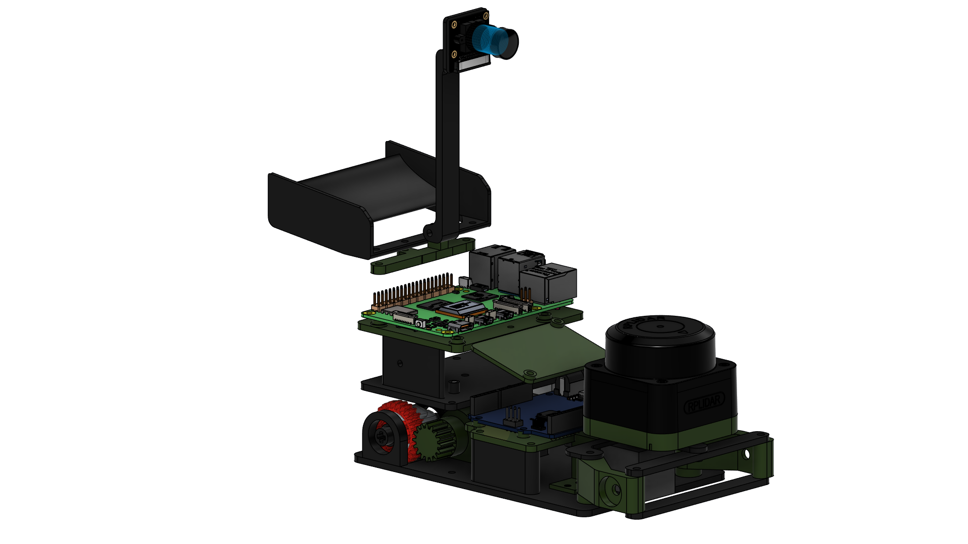
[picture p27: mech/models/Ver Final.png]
      
    </td>
  </tr>
</table>

Version 3 is the final current mechanical platform.

Unlike the smaller transition from V1 to V2, V3 involved a more complete redesign and physical rebuild. The motor drive gear was reduced again from 21 teeth to **16 teeth**, increasing the final external reduction to 1.75:1.

The rear structure was reinforced with additional pillars, the component layout was revised and new structures were created for the LiDAR / IMU, XL4015 converter and rear handling wing.

---

### 3.4.1 Final Drivetrain Change

The final external drivetrain is:

```text
16T Driver
     ↓
28T Differential

External Reduction
= 28 / 16
= 1.75:1
```

Compared with V2, this configuration provides additional theoretical torque multiplication while further reducing the theoretical maximum drivetrain speed.

After testing the different mechanical versions, the 16:28 configuration provided the most useful balance for our current robot between acceleration, usable speed, low-speed control, torque and repeated steering correction.

---

### 3.4.2 Structural Improvements

The rear section was reinforced using additional vertical supports to improve rigidity around the stacked electronics and sensor structures.

The final robot also integrates the camera support, LiDAR / IMU mount and rear handling structure into the same mechanical platform. This allows the upper sensing system to remain mechanically connected to the main chassis rather than behaving as several independent mounts.

---

## 3.5 Mechanical Evolution Summary

| Version | Driver Gear | External Ratio | Major Mechanical Change | Main Reason |
|---|---:|---:|---|---|
| V0 | Previous-generation configuration | — | Reference vehicle | Learn from previous design |
| V1 | 28T | 1.00:1 | Initial drivetrain / steering prototype | Test basic concept |
| V2 | 21T | 1.33:1 | Ackermann steering + bearings | Increase torque and precision |
| V3 | 16T | 1.75:1 | Final rebuilt platform | Further improve controllability |

---

## 3.6 Iteration Logic

The drivetrain progression demonstrates one of the clearest mechanical trade-offs in the project.

```text
Higher Speed
    ↑
    │
28:28
    │
21:28
    │
16:28
    ↓
Higher Torque / Control
```

The final ratio was not selected only because it produced more theoretical torque. It was selected because the increased reduction produced behavior that better matched the practical requirements of autonomous navigation and parking.

---

# 4. Final Mechanical Architecture



The recommended labels for the image are **Main Base, Front Steering Assembly, Steering Servo, Camera Mechanism, Motor, 16T Drive Gear, Differential, Rear Axle, Bearing Mounts, Electrical Base, UNO Base, Raspberry Pi Base, LiDAR / IMU Mount, Rear Wing and Step-down Tray**.

---

## 4.1 Mechanical Layout

The final robot uses a layered mechanical architecture.

```text
               Camera
                  │
            Camera Mount
                  │
              Pi Layer
                  │
         Electronics Layer
                  │
       ┌──────────┴──────────┐
       │                     │
Front Steering          Rear Drivetrain
       │                     │
 Ackermann             Motor + Gear
       │                     │
Front Wheels            Differential
                             │
                        Rear Wheels
```

The drivetrain and steering remain close to the lower structural layer, while the electronics and sensing systems use the vertical space above them.

This arrangement separates the major moving mechanisms from the upper computing and sensor layers while keeping the complete robot compact.

---

# 5. Drivetrain Engineering

## 5.1 Drivetrain Architecture

The final drivetrain transfers power through the following mechanical path:

```text
CHP-20GP-180 Motor
        │
        │ Internal Gearbox
        │ 19:1
        v
Motor Output Shaft
        │
        │ 16-Tooth Custom Gear
        v
28-Tooth Differential Gear
        │
        v
LEGO Differential
     ┌──┴──┐
     │     │
     v     v
 Left    Right
 Wheel   Wheel
```

This architecture combines the motor's internal 19:1 reduction with an additional 16:28 external gear reduction before power reaches the two rear wheels.

---

## 5.2 Motor Selection

### CHP-20GP-180 DC 12 V Geared Motor

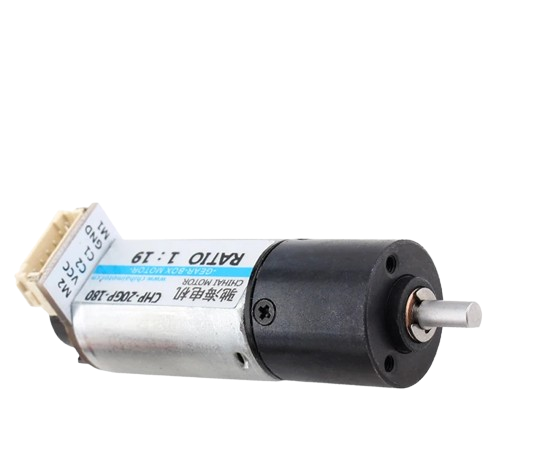
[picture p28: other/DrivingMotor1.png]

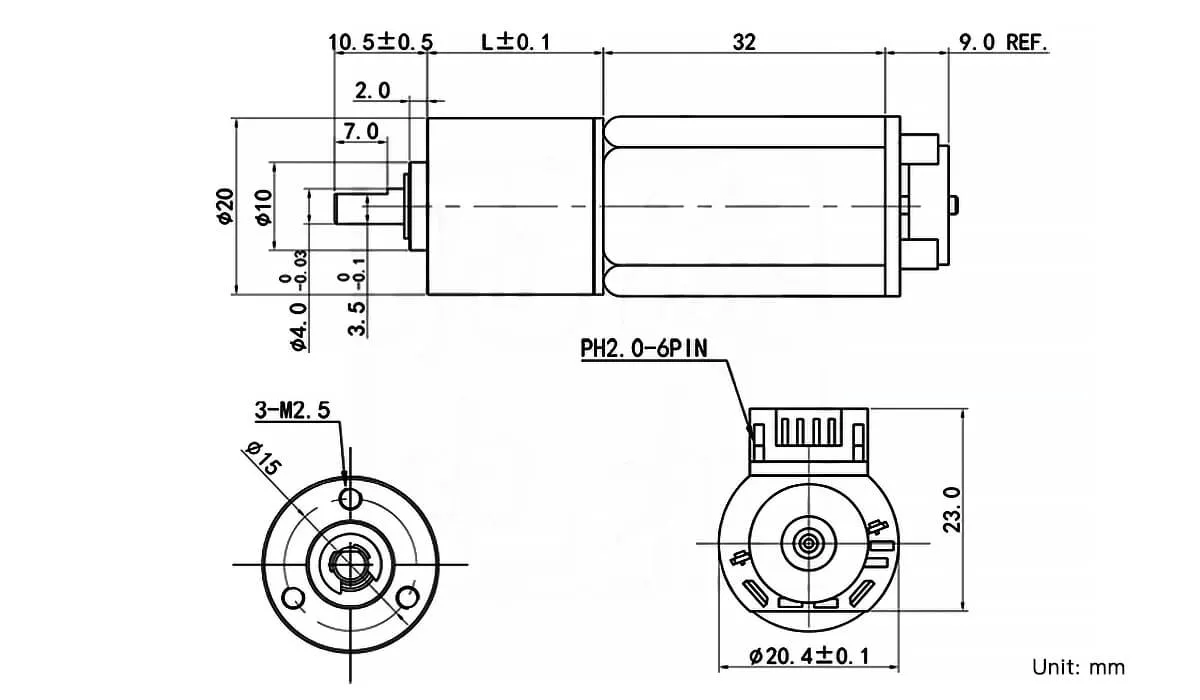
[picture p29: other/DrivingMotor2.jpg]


We selected the **CHP-20GP-180 DC geared motor** with a **19:1 internal gearbox** and dual-phase quadrature encoder.

The motor was chosen because its higher reduction provides more torque than faster variants while still maintaining a useful output speed. The integrated encoder also provides motor-rotation feedback, which is valuable for controlled finite movements.

Its physical size was suitable for our compact chassis and the motor remained usable throughout prototype testing. These characteristics made it better suited to the precision-focused behavior required by our autonomous vehicle than simply selecting the highest-speed available option.

---

### 5.2.1 Why We Prioritized the 19:1 Configuration

A faster motor configuration can increase maximum vehicle speed, but that benefit becomes less useful if the robot becomes harder to accelerate smoothly, control through corners, position accurately or park.

The 19:1 configuration therefore reflects the same design philosophy used for the external transmission. We prefer a drivetrain that gives the autonomous software enough mechanical control authority rather than maximizing theoretical speed alone.

---

### 5.2.2 Motor Encoder

The integrated dual-phase encoder measures motor rotation instead of requiring the control system to rely only on the commanded motor power.

This is especially useful when the robot needs a defined amount of drivetrain movement. Battery state, friction and loading can change the relationship between a PWM command and the real physical rotation, while an encoder directly observes rotational motion.

<table align="center">
  <tr>
    <td align="center">
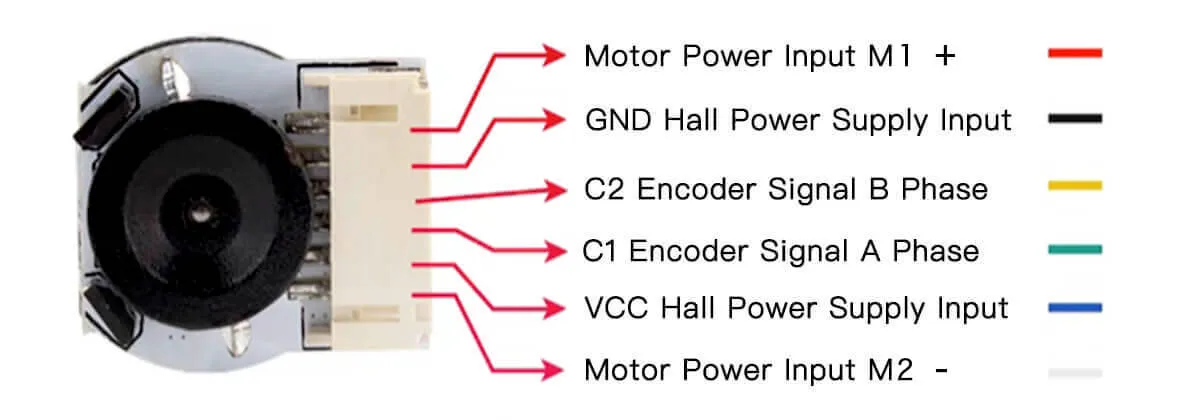
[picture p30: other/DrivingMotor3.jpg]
      
    </td>
  </tr>
</table>

### Encoder Wiring

| Wire | Function |
|---|---|
| Red | Motor power positive |
| Black | Hall-effect sensor GND |
| Yellow | Encoder Signal B |
| Green | Encoder Signal A |
| Blue | Hall-effect sensor 5 V |
| White | Motor power negative |

---

### 5.2.3 Electrical Specifications

| Specification | Value |
|---|---:|
| Voltage | 12 V DC |
| No-Load Current | ≤ 280 mA |
| Rated Current | ≤ 550 mA |
| Stall Current | ≤ 2.7 A |

---

### 5.2.4 Mechanical Specifications

| Specification | Value |
|---|---:|
| Internal Gear Ratio | 19:1 |
| No-Load Speed | ~780 RPM |
| Rated Speed | ~680 RPM |
| Rated Torque | 0.40 kg·cm / 0.039 N·m |
| Stall Torque | ≥ 2.0 kg·cm / 0.196 N·m |
| Gearbox Length | 21.5 mm |

---

### 5.2.5 Encoder Specifications

| Specification | Value |
|---|---|
| Type | AB Dual-Phase Hall |
| Resolution | ~211 PPR |
| Supply Voltage | 3.3 V / 5.0 V DC |
| Output | Square Wave |

---

## 5.3 Custom Motor Drive Gear

### 16-Tooth Motor Gear

<table align="center">
  <tr>
    <td align="center">
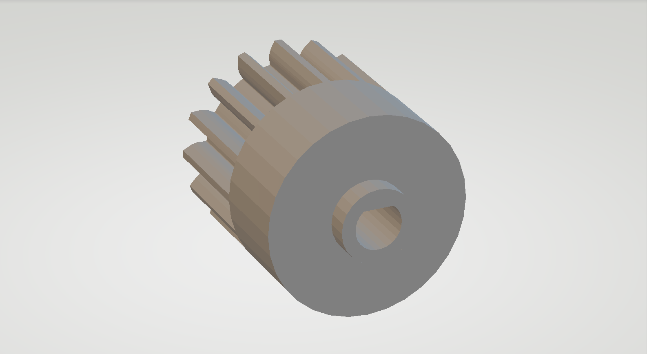
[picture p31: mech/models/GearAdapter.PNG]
      
      <p><a href="models/GearAdapter.stl">View 3D model</a></p>
    </td>
  </tr>
</table>

The final drive gear is a custom **16-tooth 3D-printed gear** that connects directly to the CHP-20GP-180 output shaft and meshes with the 28-tooth differential gear.

The center bore is designed to fit the motor shaft tightly to reduce relative slipping. Integrating the shaft interface into the gear itself also eliminates the need for a separate motor-to-gear adapter, keeping the drivetrain more compact.

---

## 5.4 Gearbox Development

### V1 — 28:28

```text
28T Driver
   ↓
28T Driven

Ratio = 1:1
```

The initial configuration used equal-size gears because it was mechanically simple and preserved the motor output speed.

Testing showed that this arrangement did not provide enough usable low-speed torque and control for the behavior we wanted.

---

### V2 — 21:28

```text
21T Driver
   ↓
28T Driven

Reduction = 28 / 21
          ≈ 1.33:1
```

Reducing the driver gear to 21 teeth increased the external reduction. The theoretical output speed decreased, while the theoretical torque increased.

The direct-fit custom gear also maintained a compact connection between the motor and differential.

---

### V3 — 16:28

```text
16T Driver
   ↓
28T Driven

Reduction = 28 / 16
          = 1.75:1
```

The final 16-tooth driver increases torque multiplication further.

The additional reduction sacrifices theoretical maximum speed, but the resulting drivetrain provides more useful low-speed stability, acceleration control and steering authority for our autonomous vehicle.

This became the final configuration.

---

## 5.5 Differential

### LEGO Technic Differential Gear — 28 Teeth

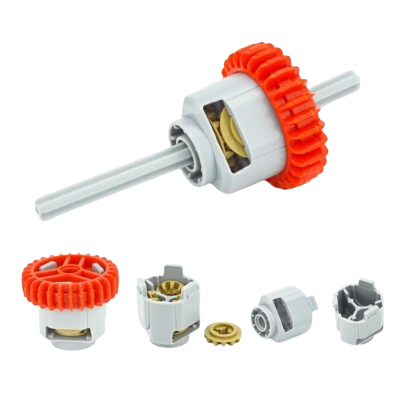
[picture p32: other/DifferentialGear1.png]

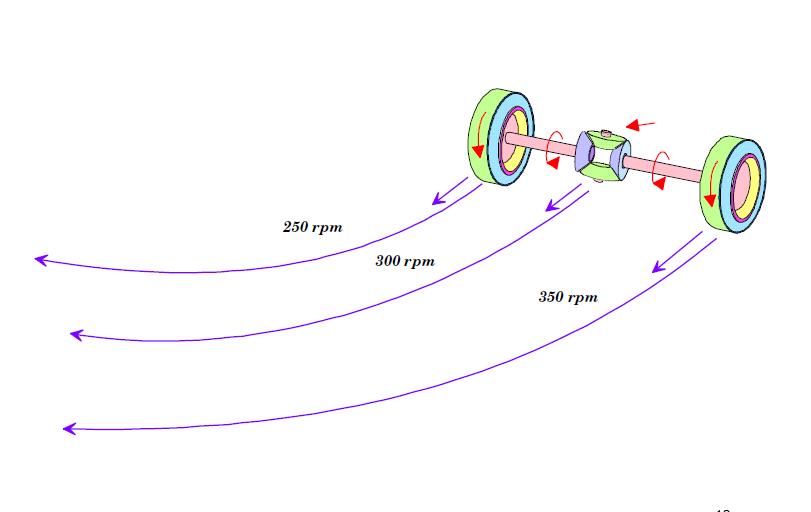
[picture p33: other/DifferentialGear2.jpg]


The LEGO Technic differential transfers power to both rear wheels while still allowing the two outputs to rotate at different speeds.

This is important because the inner and outer rear wheels travel different distances during a turn. If both rear wheels were locked to the same rotational speed, one wheel would need to slip or scrub across the field surface.

The differential therefore reduces unnecessary wheel scrub and resistance while improving maneuverability and compatibility with the automotive-style front steering geometry.

---

## 5.6 Final Drivetrain Calculation

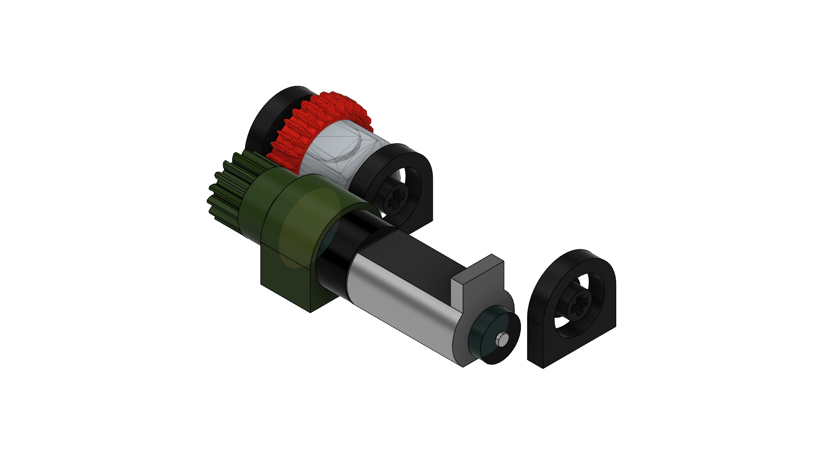
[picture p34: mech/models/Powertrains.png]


The final external drivetrain uses:

```text
Motor Output Gear = 16 teeth
Differential Gear = 28 teeth
```

---

### Step 1 — External Gear Reduction

```text
External Reduction
= Driven Gear / Driver Gear

= 28 / 16

= 1.75 : 1
```

---

### Step 2 — Rated Output RPM

Using the documented motor rated speed of approximately **680 RPM**:

```text
Output RPM
= Motor Rated RPM / External Reduction

= 680 / 1.75

≈ 389 RPM
```

Using the documented no-load speed of approximately **780 RPM**:

```text
780 / 1.75 ≈ 446 RPM
```

The approximately 389 RPM result explains why an older drivetrain description could contain a value close to 390 RPM even though the motor's documented geared-output rated speed is approximately 680 RPM. These values refer to different points in the transmission.

---

### Step 3 — Output Torque

Using the documented rated motor torque:

```text
Motor Rated Torque = 0.0392 N·m
```

The ideal theoretical torque after the external reduction is:

```text
Output Torque
= Motor Torque × External Reduction

= 0.0392 × 1.75

≈ 0.069 N·m
```

If drivetrain losses are ignored and the differential load is simplified as equally distributed between the two rear outputs:

```text
0.069 / 2

≈ 0.035 N·m per rear output
```

This per-wheel value is a simplified theoretical estimate rather than a directly measured wheel torque.

---

### 5.6.1 Calculated Final Results

| Parameter | Calculated Value |
|---|---:|
| External gear reduction | 1.75:1 |
| Differential input speed — rated | ~389 RPM |
| Differential input speed — no load | ~446 RPM |
| Ideal differential input torque | ~0.069 N·m |
| Simplified ideal torque per rear output | ~0.035 N·m |

> These calculations are ideal theoretical values and do not include mechanical losses from gear friction, bearings, differential friction, tire deformation or drivetrain alignment.

The distinction between calculated and measured values is important because the physical robot will not reproduce the ideal calculation exactly.

---

## 5.7 Wheel Selection

### LEGO Tire 43.2 × 22 ZR  
### Wheel 30.4 mm D × 20 mm Reinforced Rim

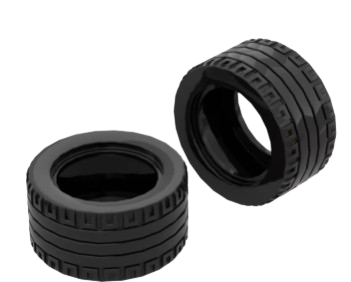
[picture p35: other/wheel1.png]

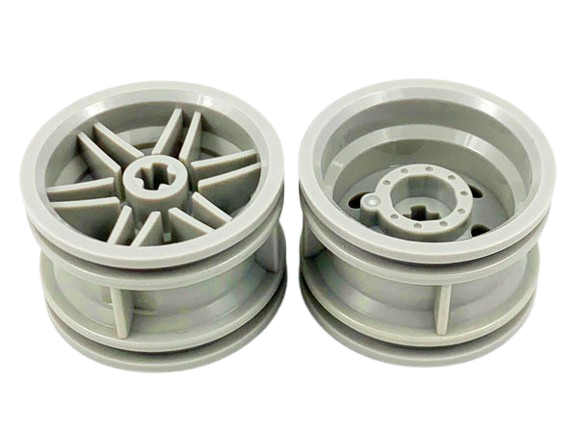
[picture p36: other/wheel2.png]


The selected wheel size provides a practical balance between ground speed, acceleration, axle torque demand, ground clearance and vehicle controllability.

A smaller wheel travels less distance for each axle revolution and therefore reduces linear vehicle speed. A larger wheel travels farther per revolution but also requires more axle torque to create the same force at the ground.

The selected LEGO wheel and tire combination works with the final drivetrain reduction while maintaining predictable handling and sufficient physical clearance for the chassis.

---

# 6. Steering System

## 6.1 Steering Architecture

The final robot uses a servo-driven **Ackermann-style front steering system**.

<table align="center">
  <tr>
    <td align="center">
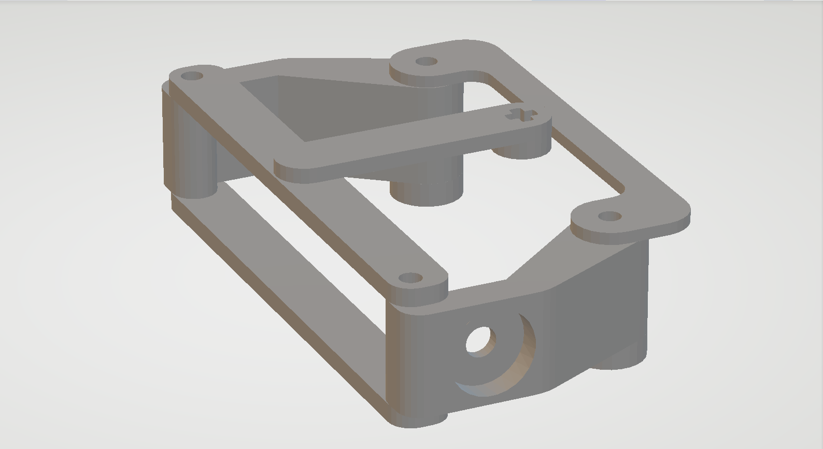
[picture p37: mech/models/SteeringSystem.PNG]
      
      <p><a href="models/SteeringSystem.stl">View 3D model</a></p>
    </td>
  </tr>
</table>

---

## 6.2 Why Ackermann-Style Steering?

During a turn, the inner front wheel travels around a smaller radius than the outer front wheel. The front wheels therefore should not ideally use exactly the same steering angle.

Conceptually:

```text
                Turn Centre
                     ●
                    /|
                   / |
          Inner   /  |  Outer
          Wheel  /   |  Wheel
```

The inward steering-arm geometry approximates this Ackermann relationship.

The purpose of the design is to reduce unnecessary tire scrub and turning resistance while creating more predictable automotive-style cornering. This geometry also works naturally with the rear differential, which allows the rear wheels to rotate at different speeds through the same turn.

---

## 6.3 Steering Components

<table align="center">
  <tr>
    <td align="center">
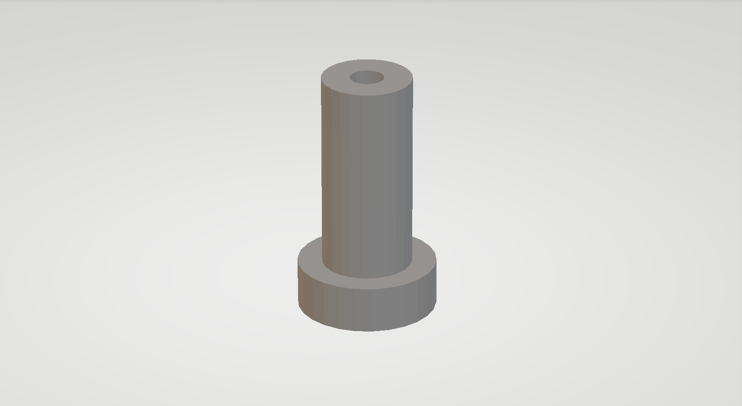
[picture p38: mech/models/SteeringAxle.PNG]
      
      <p><a href="models/SteeringAxle.stl">Steering Axle</a></p>
    </td>
    <td align="center">
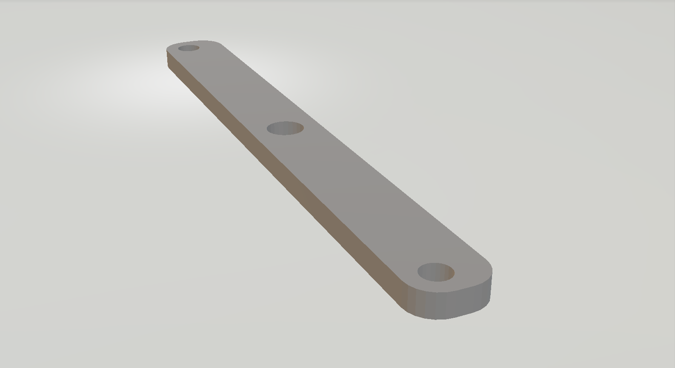
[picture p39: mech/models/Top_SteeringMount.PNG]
      
      <p><a href="models/Top_SteeringMount.stl">Top Steering Mount</a></p>
    </td>
    <td align="center">
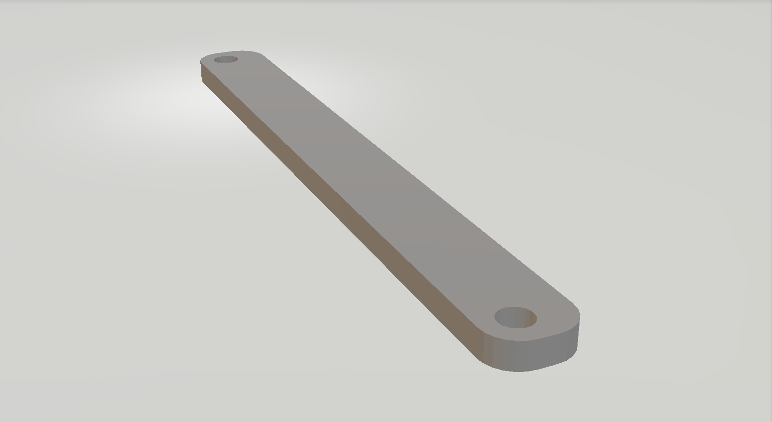
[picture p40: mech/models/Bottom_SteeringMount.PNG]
      
      <p><a href="models/Bottom_SteeringMount.stl">Bottom Steering Mount</a></p>
    </td>
  </tr>
</table>

<table align="center">
  <tr>
    <td align="center">
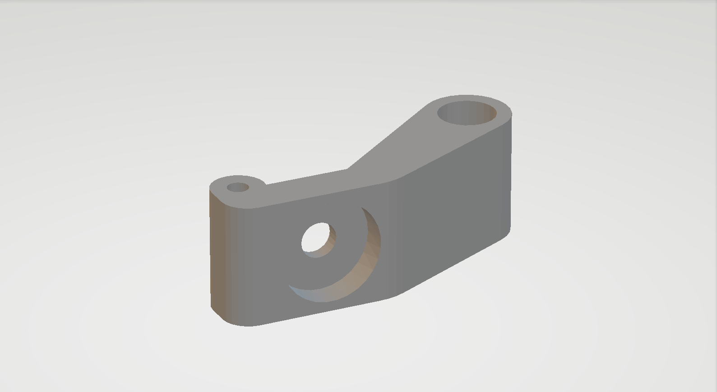
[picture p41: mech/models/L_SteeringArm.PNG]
      
      <p><a href="models/L_SteeringArm.stl">Left Steering Arm</a></p>
    </td>
    <td align="center">
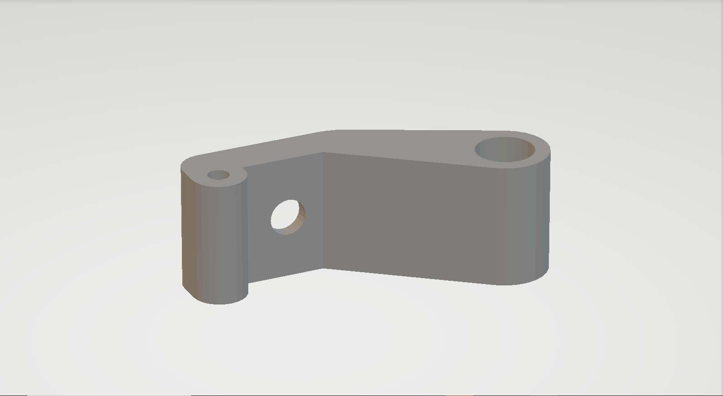
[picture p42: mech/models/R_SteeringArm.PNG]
      
      <p><a href="models/R_SteeringArm.stl">Right Steering Arm</a></p>
    </td>
    <td align="center">
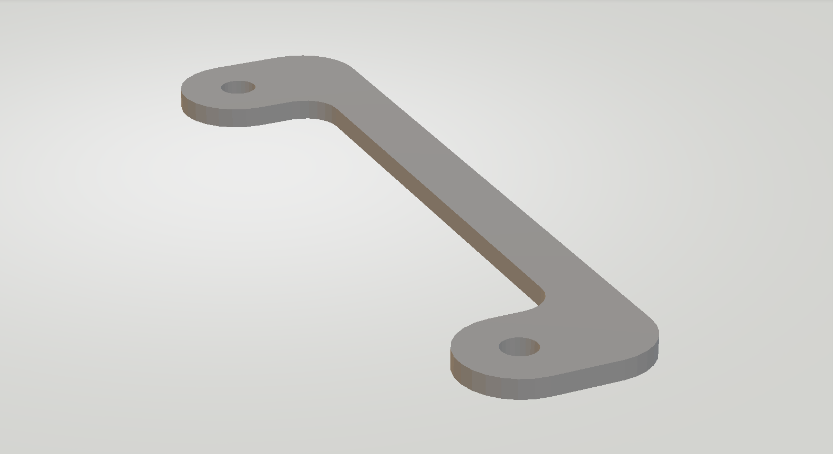
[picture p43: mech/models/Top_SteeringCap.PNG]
      
      <p><a href="models/Top_SteeringCap.stl">Top Steering Cap</a></p>
    </td>
    <td align="center">
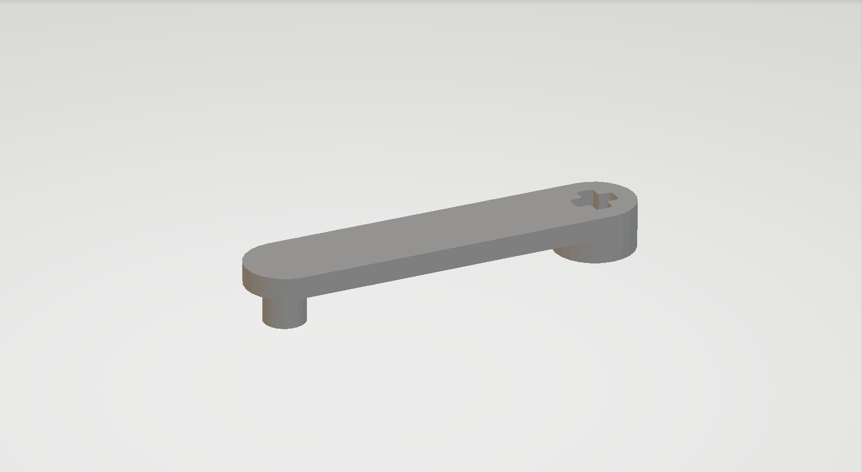
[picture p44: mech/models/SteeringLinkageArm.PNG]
      
      <p><a href="models/SteeringLinkageArm.stl">Steering Linkage Arm</a></p>
    </td>
  </tr>
</table>

### Steering Axle

The steering axle acts as the primary pivot for the steering arms. It maintains wheel alignment while still allowing the arms to rotate with minimal unwanted lateral movement.

### Steering Linkage Arm

The linkage connects the steering servo to the two front steering arms. It converts servo rotation into the push-pull motion that changes the angle of both front wheels.

### Top Steering Mount / Cap

The upper structure stabilizes the steering pivots and works together with the lower structure to maintain steering rigidity.

### Bottom Steering Mount

The lower mount supports and aligns the steering pivots.

An earlier version of this part also included a location for the light sensor used in the original sensing concept. Although the light sensor was removed from the final robot, the feature is part of the mechanical development history because it shows that the steering structure changed together with the sensing architecture.

### Left and Right Steering Arms

The steering arms connect the linkage to the front wheels. Their inward geometry produces the approximate Ackermann relationship between the inner and outer wheel angles during cornering.

---

## 6.4 Steering Servo

### GEEKSERVO 2 kg 360° Servo

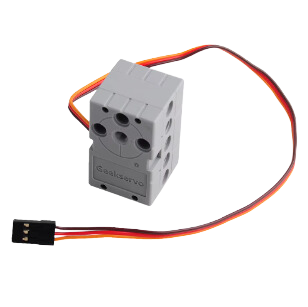
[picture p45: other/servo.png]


The GEEKSERVO was selected because it provides sufficient torque and response for the steering mechanism while remaining mechanically compatible with LEGO-style mounting.

This compatibility simplifies its integration with the hybrid custom-printed and LEGO mechanical structure. The servo has also been used through the prototype process without significant mechanical failure.

The gear mechanism can slip under excessive blocking load rather than remaining completely rigid, which may reduce mechanical damage during severe overload.

### Servo Wiring

| Wire | Function |
|---|---|
| Red | Positive |
| Brown | Ground |
| Yellow | Signal |

### Electrical Specifications

| Specification | Value |
|---|---:|
| Working Voltage | 3.3–6 V |
| Rated Voltage | 4.8 V |
| Rated Current | 200 mA |
| Stall Current | 700 mA |
| Sliding Current | 450 mA |

---

## 6.5 Servo Bracket

<table align="center">
  <tr>
    <td align="center">
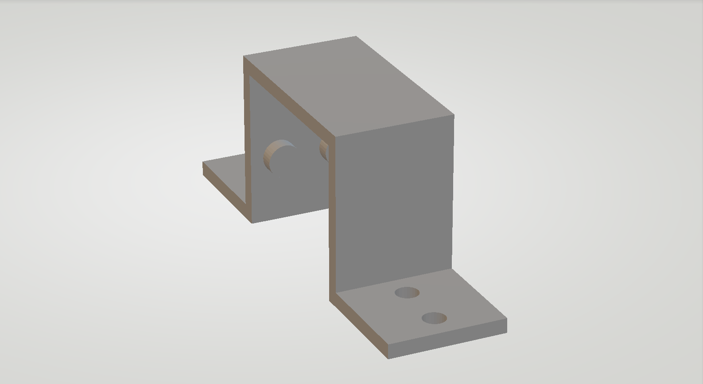
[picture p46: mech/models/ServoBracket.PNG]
      
      <p><a href="models/ServoBracket.stl">View 3D model</a></p>
    </td>
  </tr>
</table>

The servo bracket holds the steering actuator at the required height and alignment relative to the steering linkage.

Its cylindrical mounting features allow the LEGO-compatible servo to integrate directly with the surrounding structure. The part was designed to remain compact and lightweight while still being simple to print and rigid enough to prevent unwanted actuator movement.

---

# 7. Structural Design and Final 3D Components

The final chassis is divided into modular structural layers instead of being printed as one large part.

This makes individual components easier to manufacture and replace. It also allows one area of the robot to be redesigned without requiring the complete chassis to be reprinted.

The layered structure is especially useful for organizing the electronics vertically while keeping the drivetrain and steering mechanisms near the lower part of the vehicle.

---

## 7.1 Main Base

<table align="center">
  <tr>
    <td align="center">
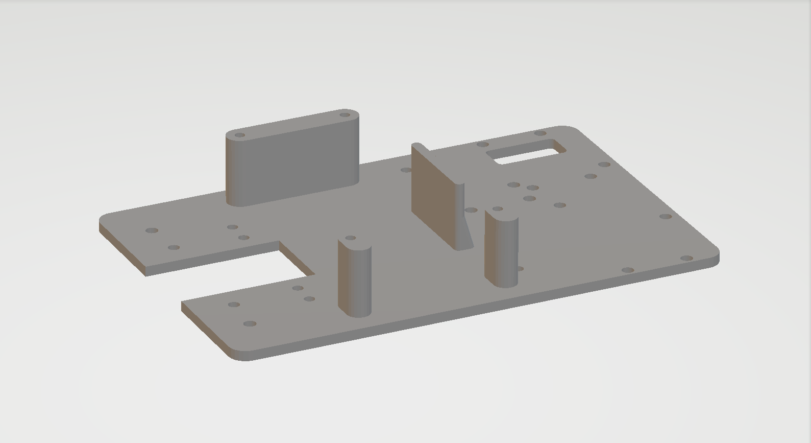
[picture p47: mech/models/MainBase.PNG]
      
      <p><a href="models/MainBase.stl">View 3D model</a></p>
    </td>
  </tr>
</table>

The Main Base is the primary structural layer of the robot. It supports the battery, Arduino UNO R4, steering servo and the main drivetrain components.

Placing several of the heavier mechanical and electrical components near the bottom of the robot helps keep the center of mass lower. The base also provides the mounting points that support the upper structural layers.

---

## 7.2 Supporting Base 1 — Electrical Base

<table align="center">
  <tr>
    <td align="center">
      
      <p><a href="models/ElecPlate.stl">View 3D model</a></p>
    </td>
  </tr>
</table>

The Electrical Base supports the LM2596 converter, PCT-21 ground connector, D1-2 positive connector, main power switch and competition start switch.

The plate also contributes to the structural support of the Raspberry Pi layer above it, so it functions as both an electronics mount and part of the stacked chassis.

---

## 7.3 Supporting Base 2 — Arduino Base

<table align="center">
  <tr>
    <td align="center">
      
      <p><a href="models/UnoPlate.stl">View 3D model</a></p>
    </td>
  </tr>
</table>

The Arduino Base supports the Arduino UNO R4 Minima and its motor-control hardware. The XL4015 assembly is also integrated around this section of the robot.

This arrangement keeps the low-level control hardware close to the drivetrain and steering system while leaving the upper layers available for high-level computing and sensors.

---

## 7.4 Supporting Base 3 — Raspberry Pi Base

<table align="center">
  <tr>
    <td align="center">
      
      <p><a href="models/PiPlate.stl">View 3D model</a></p>
    </td>
  </tr>
</table>

This layer supports the Raspberry Pi 5, Raspberry Pi I/O Expansion HAT, camera structure and rear structural supports.

Using the upper vertical space for the high-level computer keeps the Raspberry Pi away from the main drivetrain while still allowing it to remain connected to the camera, LiDAR, IMU and Arduino.

---

## 7.5 Motor Bracket

<table align="center">
  <tr>
    <td align="center">
      
      <p><a href="models/MotorBracket.stl">View 3D model</a></p>
    </td>
  </tr>
</table>

The motor bracket is a custom 3D-printed structural component that holds the CHP-20GP-180 rigidly relative to the differential.

The mount includes threaded features that allow screws to be installed without requiring separate nuts in some locations. This keeps the assembly compact while maintaining access during maintenance.

Motor alignment is mechanically important because misalignment between the 16T motor gear and the 28T differential gear can increase friction, create poor tooth engagement or increase drivetrain wear.

---

## 7.6 Rear Bearing Mount System

<table align="center">
  <tr>
    <td align="center">
      
      <p><a href="models/BearingSystem.stl">View 3D model</a></p>
    </td>
  </tr>
</table>

<table align="center">
  <tr>
    <td align="center">
      
      <p><a href="models/BearingMount.stl">Bearing Mount</a></p>
    </td>
    <td align="center">
      
      <p><a href="models/L%26R_AxleSleeve.stl">Left / Right Axle Sleeve</a></p>
    </td>
    <td align="center">
      
      <p><a href="models/Mid_AxleSleeve.stl">Middle Axle Sleeve</a></p>
    </td>
  </tr>
</table>

The rear drivetrain uses ball bearings to support the differential output shaft. The inner bearing race interfaces with the shaft through custom sleeves, while the outer race remains fixed in the printed bearing mount.

This arrangement prevents the rotating axle from sliding directly against the printed structure. It improves rotational efficiency, axle alignment, rigidity, durability and drivetrain consistency.

---

## 7.7 Rear Wing / Handling Structure

<table align="center">
  <tr>
    <td align="center">
      
      <p><a href="models/RearWing.stl">View 3D model</a></p>
    </td>
  </tr>
</table>

The rear wing is based on an **S1223 airfoil profile**, but aerodynamic performance is not its primary function on this robot.

At the relatively low operating speed of the vehicle, and with the nearby camera structure disturbing the airflow, meaningful aerodynamic downforce is expected to be very small.

The part is therefore used mainly as a structural rear element, additional support for the camera assembly and a practical handling point when carrying the robot.

This interpretation avoids claiming an aerodynamic benefit that has not been demonstrated at the robot's operating speed.

---

## 7.8 Step-Down Tray

<table align="center">
  <tr>
    <td align="center">
      
      <p><a href="models/StepdownTray.stl">View 3D model</a></p>
    </td>
  </tr>
</table>

The Step-Down Tray holds the XL4015 converter above the Arduino / motor-shield section.

The tray allows the converter to be fixed mechanically instead of depending only on the connected wiring to hold it in position. This reduces unwanted movement and improves the organization of the final electrical layout.

---

# 8. Mechanical Sensor and Electronics Integration

Mechanical design affects sensor performance directly.

A sensor may be electrically correct but still produce poor information if it is mounted at the wrong orientation, if its field of view is obstructed or if its supporting structure moves excessively.

For this reason, the chassis is designed to hold the sensors rigidly, maintain the required orientation and keep their sensing areas as clear as possible.

---

## 8.1 Camera Positioning Mechanism

<table align="center">
  <tr>
    <td align="center">
      
      <p><a href="models/CamMount.stl">View 3D model</a></p>
    </td>
  </tr>
</table>

The camera positioning mechanism allows the camera height and angle to be adjusted without redesigning the complete chassis.

A completely fixed mount would require CAD modification and reprinting whenever the team wanted to test a different camera position:

```text
Change Camera Position
        ↓
Modify CAD
        ↓
Reprint Part
        ↓
Reassemble Robot
```

The adjustable system instead allows:

```text
Change Camera Position
        ↓
Adjust Existing Mechanism
        ↓
Continue Testing
```

This reduces mechanical iteration time and allows the camera view to be tuned more quickly during testing.

---

### 8.1.1 Camera Components

<table align="center">
  <tr>
    <td align="center">
      
      <p><a href="models/CamPlate.stl">Camera Plate</a></p>
    </td>
    <td align="center">
      
      <p><a href="models/CamArm.stl">Camera Arm</a></p>
    </td>
    <td align="center">
      
      <p><a href="models/CamArmConnector.stl">Camera Arm Connector</a></p>
    </td>
  </tr>
</table>

### Camera Plate

The camera plate holds the camera rigidly so that its orientation does not change unnecessarily during autonomous operation.

### Camera Arm

The camera arm positions the camera at the required height and angle while maintaining a clear view toward the field.

### Camera Arm Connector

The connector links the camera support to the Raspberry Pi / rear structural area. This spreads the load into the surrounding chassis and improves rigidity during acceleration, braking and steering.

---

## 8.2 LiDAR and IMU Mount

<table align="center">
  <tr>
    <td align="center">
      
      <p><a href="models/LiDARMount.stl">View 3D model</a></p>
    </td>
  </tr>
</table>

The LiDAR mount holds the RPLiDAR securely while maintaining a clear scanning area around the sensor.

Its recessed centre creates space for the BNO055 underneath the LiDAR. This makes more efficient use of the vertical space, reduces congestion around the Raspberry Pi and keeps the LiDAR mechanically stable.

The IMU position also moves the device away from some of the denser electronics and wiring near the Pi. Because the BNO055 contains a magnetometer, physical separation from high-current wiring and electronics may be beneficial, although the improvement has not been quantified experimentally.

---

# 9. Manufacturing and Material Selection

Most custom components are produced by FDM 3D printing.

This manufacturing method allows the team to modify one part, print a new version and test it without waiting for a commercial chassis component. It is particularly useful for the iterative development of the drivetrain mounts, steering system and sensor structures.

---

## 9.1 3D Printer

### Bambu Lab H2D



The **Bambu Lab H2D** was used to manufacture the custom robot components.

Its printing speed and dimensional capability were useful during rapid prototype development, while the enclosed heated system and high-temperature hotend allowed the team to use engineering materials such as ABS and ABS-GF.

The large build volume was also sufficient for the major chassis plates and structural components.

---

### 9.1.1 General Specifications

| Specification | Value |
|---|---|
| Build Volume | 325 × 320 × 325 mm³ — Single Nozzle |
| Dual-Nozzle Build Volume | 300 × 320 × 325 mm³ |
| Hotend | All-Metal |
| Included Nozzle | 0.4 mm Hardened Steel |
| Maximum Nozzle Temperature | 350°C |
| Filament Diameter | 1.75 mm |
| Maximum Toolhead Speed | 1000 mm/s |
| Maximum Acceleration | 20,000 mm/s² |
| Maximum Chamber Temperature | 65°C |
| Maximum Heatbed Temperature | 120°C |
| Supported Nozzle Sizes | 0.2 / 0.4 / 0.6 / 0.8 mm |

---

### 9.1.2 Physical Dimensions

| Specification | Value |
|---|---|
| Printer Dimensions | 492 × 514 × 626 mm³ |
| Net Weight | 31 kg |

---

### 9.1.3 Build Plate

| Specification | Value |
|---|---|
| Build Plate | Flexible Steel Plate |
| Included Plate | Textured PEI |
| Supported Plates | Textured PEI / Smooth PEI |
| Maximum Heatbed Temperature | 120°C |
| Heated Chamber | Up to 65°C |

---

## 9.2 Filament Selection

### Bambu Lab ABS and ABS-GF




The custom robot uses both **ABS** and **ABS-GF**, which is glass-fiber-reinforced ABS.

---

### ABS

ABS provides a useful balance of impact toughness, strength and a relatively smooth printed surface. It also retains more flexibility than the glass-fiber-reinforced material.

For this reason, ABS is suitable for general structural components and locations where extreme stiffness is not the primary requirement.

---

### ABS-GF

ABS-GF contains glass-fiber reinforcement, which increases the material's stiffness and dimensional stability.

It is therefore useful for components where deformation or flex is more critical, although the increase in stiffness comes with lower impact toughness compared with standard ABS.

---

### 9.2.1 Material Trade-off

| Property | ABS | ABS-GF |
|---|---|---|
| Impact toughness | Higher | Lower |
| Stiffness | Lower | Higher |
| Dimensional stability | Good | Higher |
| Surface texture | Smoother | Rougher |
| Best use | General / impact-tolerant parts | Rigid structural parts |

---

### 9.2.2 Material Specifications

| Specification | Bambu Lab ABS | Bambu Lab ABS-GF |
|---|---:|---:|
| Material | ABS | Glass-Fiber Reinforced ABS |
| XY Impact Strength | 39.3 kJ/m² | 14.5 kJ/m² |
| XY Bending Strength | 62 MPa | 68 MPa |
| XY Bending Modulus | 1880 MPa | 2860 MPa |
| Z Impact Strength | 7.4 kJ/m² | 5.3 kJ/m² |
| HDT @ 0.45 MPa | 87°C | 99°C |
| Filament Diameter | 1.75 mm | 1.75 mm |

The material data shows the main trade-off clearly:

> **[ABS](https://bambulab.com/en/filament/abs) provides greater impact toughness, while [ABS-GF](https://bambulab.com/en/filament/abs-gf) provides greater stiffness and heat resistance.**

The final robot therefore does not use one material for every printed component. Material choice depends on the mechanical function and required behavior of the part.

---

# 10. Mechanical Testing and Iteration

Mechanical testing is used as part of the design process rather than only as a final check that the robot moves.

The clearest example is the drivetrain, where the external ratio changed twice because the earlier configurations did not provide the level of low-speed control we wanted.

---

## 10.1 Drivetrain Testing

| Version | Configuration | Observation | Decision |
|---|---|---|---|
| V1 | 28:28 | Insufficient low-speed torque / control | Increase reduction |
| V2 | 21:28 | Improved torque and controllability | Test further reduction |
| V3 | 16:28 | Best balance found for current robot | Selected as final |

This progression provides direct evidence that testing affected the final mechanical architecture rather than merely confirming a design that had already been selected.

---

## 10.2 Testing Logic

```text
V1 — 28:28
      │
      │ Low-speed control insufficient
      v
V2 — 21:28
      │
      │ Improved, but further torque desired
      v
V3 — 16:28
      │
      v
Final Configuration
```

The progression demonstrates the trade-off between theoretical maximum speed and usable torque/control.

---

## 10.3 Steering Testing

The steering mechanism was evaluated together with the software rather than only from CAD geometry.

Dedicated steering-calibration tools later showed that the real robot did not turn exactly according to the original assumed steering model. The measured vehicle turned approximately **21% more than the original assumed full-lock value**.

This is important because the physical steering geometry directly affects the Pure Pursuit model used by the software. Measuring the assembled robot therefore provides more useful information than assuming the printed mechanism behaves exactly like the ideal CAD design.

---

## 10.4 Additional Mechanical Measurements

The following values should be measured directly from the completed Version 3 robot.

| Measurement | Final Value |
|---|---|
| Robot length | 255mm |
| Robot width | 150mm |
| Robot height | 230mm |
| Robot mass | 855g (w/Battery) |
| Wheelbase | 140mm |
| Front track width | 120mm |
| Rear track width | 115mm |

---

# 11. Mechanical Trade-offs and Engineering Decisions

The final mechanical platform contains several deliberate trade-offs.

| Decision | Benefit | Cost / Trade-off | Final Reason |
|---|---|---|---|
| 19:1 motor gearbox | Higher torque | Lower motor speed | Better low-speed behavior |
| 16:28 external reduction | Additional torque multiplication | Reduced wheel speed | Precision prioritized |
| Differential | Reduced wheel scrub during turns | More mechanical parts | Better cornering behavior |
| Ackermann-style steering | More appropriate inner/outer wheel geometry | Increased design complexity | Better automotive motion |
| Bearings | Lower shaft friction and better alignment | Additional components | Improved reliability |
| Adjustable camera mount | Rapid physical tuning | More parts / joints | Faster iteration |
| Layered chassis | Efficient use of volume | Taller structure | Better electronics organization |
| ABS-GF | Higher stiffness | Lower impact toughness | Used where rigidity is critical |
| ABS | Higher toughness | Lower stiffness | Used where impact tolerance is useful |
| Rear wing as handle | Strong handling point | Additional mass | Practical handling / support |
| Custom printed drivetrain parts | Rapid modification | Potential wear / tolerances | Enables fast prototype iteration |

---

## 11.1 Most Important Mechanical Decision

The most important mechanical trade-off in the project is:

> **Maximum speed vs. torque and controllability.**

Our prototype development showed that maximizing drivetrain speed did not create the most useful autonomous vehicle.

The final system therefore combines a **19:1 internal motor gearbox** with a **1.75:1 external reduction**. This sacrifices theoretical maximum wheel speed in exchange for greater torque multiplication and more controllable behavior at lower speed.

That trade-off directly supports the steering corrections, close obstacle passes and parking movements required by the autonomous software.

---

# 12. Mechanical Risks and Failure Modes

Mechanical reliability also requires the team to consider what can go wrong rather than only documenting the intended geometry.

| Mechanical Risk / Failure Mode | Possible Effect | Design Response |
|---|---|---|
| Insufficient drivetrain torque | Poor acceleration / inconsistent low-speed movement | Increase external reduction |
| Excessive drivetrain speed | Harder steering and parking control | Select higher reduction |
| Gear misalignment | Friction, wear, poor power transfer | Rigid motor bracket |
| Rear axle bending / friction | Inconsistent drivetrain behavior | Bearing-supported axle |
| Steering play | Inconsistent wheel angle | Rigid steering mounts and pivots |
| Printed-part deformation | Misalignment | Use ABS-GF where additional stiffness is needed |
| Camera vibration | Unstable image | Rigid camera plate and support |
| LiDAR mounting error | Incorrect scan geometry | Dedicated rigid LiDAR mount |
| Electronics structure flex | Sensor / wiring movement | Reinforced rear structure |
| Mechanical obstruction | Limited sensor view | Elevated / dedicated sensor mounts |

The important connection is that several of these mechanical failures would also appear as software or sensing problems. For example, a moving camera mount can look like a vision problem, and an incorrectly aligned LiDAR mount can look like a localization problem.

Mechanical stability is therefore part of the reliability of the complete autonomous system.

---

# 13. CAD Files and Reproducibility

The final mechanical platform is designed so that another builder can reproduce the structure using the CAD / STL files provided in the repository.

The detailed assembly sequence is documented separately in:

[`../BUILD.md`](../BUILD.md)

This README explains the design reasoning, while `BUILD.md` explains the order in which the mechanical structure should be manufactured and assembled.

---

## 13.1 Final Mechanical Files

| Component | Model | STL File |
|---|---|---|
| Main Base |  | [`MainBase.stl`](models/MainBase.stl) |
| Electrical Base |  | [`ElecPlate.stl`](models/ElecPlate.stl) |
| Arduino Base |  | [`UnoPlate.stl`](models/UnoPlate.stl) |
| Raspberry Pi Base |  | [`PiPlate.stl`](models/PiPlate.stl) |
| 16T Driver Gear |  | [`GearAdapter.stl`](models/GearAdapter.stl) |
| Motor Bracket |  | [`MotorBracket.stl`](models/MotorBracket.stl) |
| Bearing System |  | [`BearingSystem.stl`](models/BearingSystem.stl) |
| Bearing Mount |  | [`BearingMount.stl`](models/BearingMount.stl) |
| Left / Right Axle Sleeve |  | [`L&R_AxleSleeve.stl`](models/L%26R_AxleSleeve.stl) |
| Middle Axle Sleeve |  | [`Mid_AxleSleeve.stl`](models/Mid_AxleSleeve.stl) |
| Steering System |  | [`SteeringSystem.stl`](models/SteeringSystem.stl) |
| Steering Axle |  | [`SteeringAxle.stl`](models/SteeringAxle.stl) |
| Top Steering Mount |  | [`Top_SteeringMount.stl`](models/Top_SteeringMount.stl) |
| Bottom Steering Mount |  | [`Bottom_SteeringMount.stl`](models/Bottom_SteeringMount.stl) |
| Left Steering Arm |  | [`L_SteeringArm.stl`](models/L_SteeringArm.stl) |
| Right Steering Arm |  | [`R_SteeringArm.stl`](models/R_SteeringArm.stl) |
| Top Steering Cap |  | [`Top_SteeringCap.stl`](models/Top_SteeringCap.stl) |
| Steering Linkage |  | [`SteeringLinkageArm.stl`](models/SteeringLinkageArm.stl) |
| Servo Bracket |  | [`ServoBracket.stl`](models/ServoBracket.stl) |
| Camera Mount |  | [`CamMount.stl`](models/CamMount.stl) |
| Camera Plate |  | [`CamPlate.stl`](models/CamPlate.stl) |
| Camera Arm |  | [`CamArm.stl`](models/CamArm.stl) |
| Camera Connector |  | [`CamArmConnector.stl`](models/CamArmConnector.stl) |
| LiDAR / IMU Mount |  | [`LiDARMount.stl`](models/LiDARMount.stl) |
| Rear Wing |  | [`RearWing.stl`](models/RearWing.stl) |
| Step-Down Tray |  | [`StepdownTray.stl`](models/StepdownTray.stl) |

---

# 14. Final Mechanical Configuration

The final Version 3 drivetrain uses the **CHP-20GP-180 DC geared motor** with its **19:1 internal reduction**, integrated dual-phase encoder, custom **16-tooth motor gear**, LEGO Technic **28-tooth differential**, **1.75:1 external reduction**, bearing-supported rear axle and LEGO wheel system.

The steering system uses the **GEEKSERVO** together with the custom servo bracket, steering linkage, left and right steering arms, steering axle and upper/lower mounting structure. The geometry approximates Ackermann steering so that the inner and outer wheels can follow different turning radii.

The main chassis is formed by the **Main Base**, **Electrical Base**, **Arduino Base** and **Raspberry Pi Base**, together with the reinforced rear structure and rear handling wing.

Sensor mounting is integrated mechanically through the adjustable camera mechanism and dedicated LiDAR / IMU mount. These structures are intended to maintain sensor alignment while allowing the camera position to be tuned during testing.

The custom components are manufactured primarily using the **Bambu Lab H2D** with **ABS** and **ABS-GF**. The modular printed architecture allows individual mechanical parts to be changed without rebuilding the entire robot.

---

# Final Mechanical Summary

The mechanical development of YBR-SUNFLOWER progressed from a previous-generation reference vehicle through three current-generation mechanical stages.

```text
Previous-Generation Reference
            ↓
Basic Mechanical Prototype
            ↓
Torque + Steering Improvement
            ↓
Complete Mechanical Rebuild
            ↓
Final Competition Platform
```

The final robot reflects several deliberate engineering decisions.

Torque and low-speed controllability were prioritized over maximum theoretical speed, which led to the progression from 28:28 to 21:28 and finally 16:28 external gearing. The rear differential and Ackermann-style steering were selected to better support automotive-style cornering, while bearings improved drivetrain alignment and reduced direct axle friction against printed components.

The chassis uses modular printed layers so that mechanical parts can be redesigned and replaced independently. Material selection is based on the different stiffness and toughness characteristics of ABS and ABS-GF, while the adjustable camera structure and dedicated LiDAR / IMU mount allow sensor requirements to influence the mechanical design directly.

The final mechanical platform is therefore not simply a set of selected parts. It is the result of repeated engineering iteration:

> **Design → Build → Test → Identify → Modify → Validate**

Each major mechanical change was made to move the robot toward greater controllability, structural reliability and repeatable autonomous performance.

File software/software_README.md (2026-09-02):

# Software Architecture & Autonomous Navigation

This document describes the complete software architecture of the **YBR-SUNFLOWER WRO 2026 Future Engineers robot**, including code organization, controller communication, localization, path generation, Pure Pursuit steering, computer vision, traffic-pillar handling, sensor fusion, parking, failure handling, testing, tuning, simulation, and software engineering decisions.

The purpose of this document is not only to describe what the code does, but also to explain:

- why the final software architecture was selected,
- how the software is divided into independent modules,
- how the Raspberry Pi and Arduino divide responsibilities,
- how the robot estimates its position on the WRO field,
- why we use localization and path following instead of relying only on reactive camera steering,
- why Pure Pursuit is used for path tracking,
- how red and green traffic pillars are detected and incorporated into the navigation path,
- how information from LiDAR, IMU, camera, and drivetrain motion is combined,
- how abnormal and low-confidence conditions are handled,
- how simulation and real-world testing are used for tuning,
- which performance metrics are used to evaluate the system,
- what limitations remain,
- and how another team can run and understand the competition software.

---

# Contents

1. [Software Engineering Overview](#1-software-engineering-overview)
2. [Software Requirements, Constraints and Design Philosophy](#2-software-requirements-constraints-and-design-philosophy)
3. [Codebase Architecture](#3-codebase-architecture)
4. [Competition Runtime and Control Flow](#4-competition-runtime-and-control-flow)
5. [Raspberry Pi ↔ Arduino Communication](#5-raspberry-pi--arduino-communication)
6. [Localization — Knowing Where We Are](#6-localization--knowing-where-we-are)
7. [Path Generation and Track Following](#7-path-generation-and-track-following)
8. [Obstacle Detection and Traffic-Pillar Strategy](#8-obstacle-detection-and-traffic-pillar-strategy)
9. [Parking Strategy](#9-parking-strategy)
10. [Sensor Fusion and Information Arbitration](#10-sensor-fusion-and-information-arbitration)
11. [Edge Cases, Safety and Failure Handling](#11-edge-cases-safety-and-failure-handling)
12. [Testing, Simulation and Tuning](#12-testing-simulation-and-tuning)
13. [Performance Metrics and Validation](#13-performance-metrics-and-validation)
14. [Software Development and Engineering Decisions](#14-software-development-and-engineering-decisions)
15. [Known Limitations and Future Improvements](#15-known-limitations-and-future-improvements)
16. [Running and Reproducing the Software](#16-running-and-reproducing-the-software)
17. [Final Software Architecture](#17-final-software-architecture)

---

# 1. Software Engineering Overview

The final YBR-SUNFLOWER software is built around one central idea:

> **Instead of continuously asking "what should the robot steer away from?", the robot asks "where am I on the field, where should I be, and how should I get there?"**

Our earlier approach relied more heavily on immediately reacting to what the camera could see.

The limitation of a camera-dominant reactive approach is that the robot mainly knows what is visible **at the current moment**.

Changes in:

- shadows,
- reflections,
- lighting,
- camera visibility,
- or temporary obstruction

can therefore affect the information available to the navigation system.

robot_sim

The WRO field has known geometry.

The final software therefore uses this knowledge to estimate the robot's position on the field and drive a planned geometric path.

This changes the navigation problem into three primary questions:

1. **Where am I?**
2. **Where should I be?**
3. **How should I steer from my current position toward that target?**

The final system answers them using:

```text
Where am I?
→ LiDAR + IMU + motion model
→ Localization

Where should I be?
→ Racing Line

How do I get there?
→ Pure Pursuit
```

The camera has a more specialized role. It identifies red and green traffic pillars and estimates their position. Instead of switching the robot into a completely different obstacle controller, the software modifies the existing racing line around the detected pillar. The same Pure Pursuit controller then follows the modified path.

---

## 1.1 Final Autonomous Software Concept

```text
                    ENVIRONMENT
                         |
         +---------------+---------------+
         |               |               |
         v               v               v
       LiDAR           Camera           IMU
         |               |               |
         |               v               |
         |        Pillar Detection       |
         |               |               |
         +-------> Localization <---------+
                         |
                         v
                 Robot Pose Estimate
                 (x, y, heading)
                         |
                         +-------------------------+
                         |                         |
                         v                         v
                  Racing Line                Block Map
                         |                         |
                         +------------+------------+
                                      |
                                      v
                              Modified Path
                                      |
                                      v
                                Pure Pursuit
                                      |
                                      v
                             Steering + Speed
                                      |
                               USB Serial
                                      |
                                      v
                              Arduino UNO R4
                                  |       |
                                  v       v
                               Motor    Steering
```

---

## 1.2 Criterion 3 Evidence Map

| Level 6 Requirement | Evidence in This Document |
|---|---|
| Software architecture and modularity | Sections 3–4 |
| Control / state flow | Section 4 |
| Algorithm reasoning | Sections 6–10 |
| Localization strategy | Section 6 |
| Lane / path-following strategy | Section 7 |
| Obstacle strategy | Section 8 |
| Correct red / green passing logic | Section 8 |
| Parking strategy | Section 9 |
| Sensor fusion | Section 10 |
| Edge-case handling | Section 11 |
| Testing and tuning process | Section 12 |
| Performance metrics | Section 13 |
| Engineering trade-offs | Section 14 |
| Known limitations | Section 15 |
| Reproducibility | Section 16 |

---

# 2. Software Requirements, Constraints and Design Philosophy

The software must control a fully autonomous vehicle under randomized WRO competition conditions.

The system therefore cannot depend on:

- one manually selected starting heading,
- one fixed obstacle arrangement,
- one fixed camera image,
- or continuous human correction.

---

## 2.1 Main Software Requirements

The final software must:

- initialize all required hardware,
- wait for the physical competition start button,
- estimate the vehicle's position,
- determine the required driving direction,
- follow a repeatable path,
- respond to localization uncertainty,
- detect red and green traffic pillars,
- pass each pillar on the required side,
- maintain sufficient wall clearance,
- execute the parking sequence,
- stop when the round is completed,
- respect the competition time limit,
- and stop the actuators if the software exits unexpectedly.

---

## 2.2 Software Constraints

| Constraint | Software Response |
|---|---|
| Random starting orientation | Localization + automatic direction selection |
| Known field geometry | Field map used for localization |
| Limited camera reliability under lighting variation | Camera used mainly for colored traffic pillars |
| LiDAR cannot determine pillar color | Camera and LiDAR assigned different roles |
| IMU can drift | LiDAR geometry provides precise heading correction |
| Localization can become uncertain | Pose confidence tracked |
| Steering actuator has physical lag | Steering-rate handling and measured response |
| Camera processing is expensive | Camera pipeline runs at a slower cadence |
| Limited competition runtime | 180-second software timeout |
| Real robot differs from ideal geometry | Steering calibration tools |
| Field testing is time-consuming | Simulator runs real navigation code without hardware |
| Many parameters require tuning | TOML configuration files |
| Software may terminate unexpectedly | `finally` cleanup stops motor and centers steering |

---

## 2.3 Software Design Philosophy

The main software principles are:

### 1. Separate hardware access from competition behavior

Tasks should not directly construct hardware interfaces. Instead, managers and context objects isolate hardware-specific behavior.

### 2. Represent the robot in field coordinates

Whenever possible, decisions are based on:

```text
x
y
heading
```

rather than raw pixels or one distance reading.

### 3. Use one path-following controller

Normal navigation and obstacle avoidance should use the same steering architecture whenever possible.

### 4. Measure physical behavior instead of relying only on assumptions

Servo response and steering geometry are measured using dedicated tools.

### 5. Make tuning parameters editable without changing Python code

Competition tuning belongs in configuration files.

### 6. Fail safely

If execution terminates, the motor should not intentionally continue running.

---

# 3. Codebase Architecture

The competition software is divided between:

- **Arduino UNO R4 Minima**
- **Raspberry Pi 5**

The Arduino performs low-level actuator and encoder operations, while the Raspberry Pi performs the higher-level autonomous logic.

---

## 3.1 Controller Responsibility

```text
Raspberry Pi 5
────────────────────────
Perception
Localization
Field Model
Object Detection
Path Generation
Pure Pursuit
Speed Selection
Competition Logic
        |
        | USB Serial
        v
Arduino UNO R4 Minima
────────────────────────
Motor Output
Servo Output
Encoder Reading
Start Button
Distance-Based Motor Move
```

---

## 3.2 Arduino Program

The Arduino competition firmware is stored in:

```text
src/Arduino/Main.ino
```

Its responsibilities include:

- reading the quadrature encoder,
- controlling the drive motor,
- controlling the steering servo,
- monitoring the competition start button,
- receiving commands from the Raspberry Pi,
- and returning status responses.

The Arduino intentionally does not handle the high-level competition strategy. This keeps the low-level controller focused on reliable and deterministic hardware operations.

---

## 3.3 Raspberry Pi Program Structure

The Raspberry Pi software is stored in:

```text
src/Raspberrypi/
```

The code is separated so that:

> **"How the hardware works" and "what the robot should do" do not need to exist in the same module.**

The main structure is:

```text
src/Raspberrypi/
│
├── main.py
│
├── tasks/
│   ├── base_task.py
│   ├── path_task.py
│   ├── qualification/
│   └── final/
│
├── classes/
│   ├── task_context.py
│   ├── motor_manager.py
│   ├── lidar_manager.py
│   ├── compass_manager.py
│   ├── navigation_manager.py
│   ├── field_map.py
│   ├── racing_line.py
│   ├── pure_pursuit.py
│   ├── object_solver.py
│   ├── block_map.py
│   ├── steering_calibrator.py
│   └── debug_view.py
│
├── utils/
│
├── test_navigation.py
├── test_driving.py
├── test_steering.py
├── test_color_picker.py
│
├── pyproject.toml
└── uv.lock
```

---

### 3.3.1 Main Entry Point

### `main.py`

The main entry point selects which competition task to run.

Example:

```bash
uv run python main.py qualification
```

or:

```bash
uv run python main.py final
```

---

### 3.3.2 Task Layer

### `tasks/base_task.py`

Contains the common competition lifecycle:

```text
Wait for Start
      ↓
Initialize Run
      ↓
Setup Task
      ↓
Run Control Loop
      ↓
Finish Safely
```

### `tasks/path_task.py`

Contains the common path-driving logic shared by the competition rounds.

Responsibilities include:

- lap progress,
- localization,
- target-point selection,
- steering,
- speed selection,
- lost-pose handling,
- and safety.

### `tasks/qualification/`

Open Challenge behavior.

The qualification task largely reuses the standard path-driving architecture with its own configuration.

### `tasks/final/`

Obstacle Challenge behavior.

This adds:

- traffic-pillar detection,
- block mapping,
- racing-line deformation,
- and final-round behavior

on top of the common path-driving system.

---

### 3.3.3 Configuration Files

Each competition task uses a configuration file:

```text
tasks/*/config.toml
```

Tunable parameters include values such as:

- speed,
- lookahead,
- clearances,
- path settings,
- obstacle settings,
- and controller limits.

This means competition tuning can normally be performed without editing the Python implementation.

---

## 3.4 Core Software Classes

| File | Responsibility |
|---|---|
| `task_context.py` | Creates and initializes subsystems in the correct order and performs shutdown |
| `motor_manager.py` | Raspberry Pi ↔ Arduino serial communication |
| `lidar_manager.py` | RPLiDAR communication and 360-degree distance representation |
| `compass_manager.py` | BNO055 heading interface |
| `navigation_manager.py` | Field localization / particle filter |
| `field_map.py` | Geometric representation of the WRO field |
| `racing_line.py` | Desired closed path around the field |
| `pure_pursuit.py` | Converts robot pose + target point into steering |
| `object_solver.py` | Camera-based traffic-pillar detection and range estimation |
| `block_map.py` | Stores detected traffic pillars in field coordinates |
| `steering_calibrator.py` | Estimates real steering geometry |
| `debug_view.py` | Live visualization of localization and navigation |

---

## 3.5 Software-Layer Architecture

```text
                   COMPETITION TASK
                         |
                         v
                  Qualification / Final
                         |
                         v
                      PathTask
                         |
        +----------------+----------------+
        |                |                |
        v                v                v
   Localization     Racing Line      Object Map
        |                |                |
        +----------------+----------------+
                         |
                         v
                    Pure Pursuit
                         |
                         v
                  Motor Manager
                         |
                         v
                      Arduino
```

---

## 3.6 Active Competition Code vs Legacy / Experimental Code

### Active competition paths

```text
main.py
tasks/
classes/
utils/
tasks/qualification/
tasks/final/
```
---

# 4. Competition Runtime and Control Flow

The robot does not use one large function containing all competition logic. Instead, every competition round uses the same lifecycle.

---

## 4.1 Main Competition State Flow

```text
POWER ON
    |
    v
INITIALIZE HARDWARE
    |
    v
WAIT_FOR_START
    |
    v
CAPTURE INITIAL HEADING
    |
    v
SETUP
    |
    v
RUN CONTROL LOOP
    |
    +--------------------+
    |                    |
    | Finished?          | Timeout?
    |                    |
    +---------+----------+
              |
              v
            FINISH
              |
              v
      STOP MOTOR / CENTER
```

This state flow is implemented through the task architecture rather than through one monolithic state machine.

---

## 4.2 Base Task Runtime

The common runtime is implemented in `tasks/base_task.py`.

```python
def run(self):
    self.context.wait_for_start()
    self.context.compass.set_initial_heading()
    self.start_time = time.monotonic()

    try:
        self.setup()
        while not self.is_finished():
            if self.timed_out:
                print(f"Time limit ({self.max_runtime_s}s) reached - stopping.")
                break

            self.tick += 1
            self.step()

            if self.status_every and self.tick % self.status_every == 0:
                print(self.status())

            time.sleep(LOOP_DELAY_S)

    except KeyboardInterrupt:
        print("\nInterrupted by user.")

    finally:
        self.finish()
```

The loop delay is:

```text
LOOP_DELAY_S = 0.02 s
```

which gives a theoretical loop frequency of approximately:

```text
1 / 0.02 = 50 Hz
```

Actual iteration time can be lower depending on sensor and processing workload.

---

### 4.2.1 Why the `finally` Block Matters

The `finally` block is an important safety feature.

Whether the run finishes because of:

- normal task completion,
- the 180-second timeout,
- Ctrl-C,
- or a Python exception,

the cleanup code is still executed.

The final cleanup stops the drivetrain and returns the steering system to its safe state. This prevents a software exception from intentionally leaving the previous drive command active.

---

## 4.3 One Path-Following Tick

The normal path-driving loop performs the following sequence:

```python
def step(self):
    # 1. estimate how far the robot moved
    distance = self._travelled(dt)
    context.nav.report_motion(distance, self._turned(distance))

    # 2. obtain the current pose
    pose = context.nav.get_pose()

    # 3. update track progress and localization state
    self._track_progress(pose)
    self._update_lost_state(pose, now)

    # 4. choose the target point
    self.target = self.target_point(pose)

    # 5. calculate and rate-limit steering
    wanted = self.pursuit.steering(self._lead_pose(pose), self.target)
    self.steer_command = self._limit_steer_rate(wanted, dt)

    # 6. choose safe driving speed
    self.speed = self._choose_speed(pose)

    # 7. send one drive command
    context.motor.drive(self.steer_command, self.speed)
```

Conceptually:

```text
Motion Estimate
      ↓
Localization
      ↓
Track Progress
      ↓
Pose Confidence
      ↓
Target Point
      ↓
Pure Pursuit
      ↓
Steering Rate Limit
      ↓
Speed Selection
      ↓
Arduino Command
```

---

## 4.4 Obstacle-Round Processing Cadence

Camera processing is significantly more computationally expensive than a simple steering-control loop. Therefore, traffic-pillar detection does not need to run on every loop iteration. The final task runs camera detection at a slower rate and stores the detected results in the block map for use by the navigation system.

Example structure:

```python
def step(self):
    if self.tick % CAMERA_EVERY_N_TICKS == 0:
        self._update_detections()

    super().step()
```

This separates:

```text
High-rate path control
```

from:

```text
Lower-rate camera perception
```

The block map persists between camera frames, so the steering system does not lose a known pillar simply because the camera pipeline is not running on the current tick.

---

## 4.5 Competition Timeout

The software enforces the WRO run time limit through:

```text
max_runtime_s = 180 s
```

If the software reaches this limit, the control loop exits and the final cleanup is performed. This provides an explicit upper limit on autonomous execution.

---

# 5. Raspberry Pi ↔ Arduino Communication

The Raspberry Pi and Arduino run separate programs and communicate through USB Serial at 115200 baud. The communication protocol is intentionally kept small and human-readable, making it easier to understand, test, and debug.

---

## 5.1 Command Format

```text
<steering angle>,<speed>,<distance>\n
```

Example:

```text
30,55,0
```

---

## 5.2 Command Fields

### Steering Angle

```text
Negative = Left
0        = Center
Positive = Right
```

### Speed

```text
Positive = Forward
Negative = Reverse
0        = Stop
```

### Distance

The distance field represents a requested amount of motor-shaft rotation.

```text
distance = 0
```

means continuous driving until another command changes the drivetrain.

A non-zero value requests a finite encoder-controlled movement.

---

## 5.3 Arduino Response Messages

| Response | Meaning |
|---|---|
| `READY` | Arduino initialized |
| `Start` | Competition start switch triggered |
| `OK` | Continuous command accepted |
| `t` | Fixed-distance movement completed |
| `ERR` | Invalid command |

---

## 5.4 Why Use a Small Text Protocol?

Advantages include:

- easy debugging in a terminal,
- easy logging,
- human-readable commands,
- simple Arduino parser,
- low implementation complexity.

The trade-off is that text serialization is less compact than a binary protocol. For the relatively small amount of control data exchanged between the boards, simplicity was prioritized.

Detailed pin and electrical information is documented in:

[`../elec/elec_README.md`](../elec/elec_README.md)

---

# 6. Localization — Knowing Where We Are

The WRO field has known geometry. Rather than detecting only immediate wall position, the robot estimates its pose on this known field.

The pose is represented as:

```text
Pose
├── X position
├── Y position
├── Heading
└── Confidence
```

---

## 6.1 Localization Principle

For a given robot position and orientation, the surrounding field geometry produces a characteristic LiDAR distance pattern.

The software reverses this relationship:

> Given the LiDAR scan that we actually observe, which possible robot position best explains those measurements?

The final implementation uses a **particle filter**.

---

## 6.2 Particle Filter

The localization system begins with multiple possible robot poses.

The current implementation uses approximately:

```text
500 particles
```

Each particle represents a hypothesis:

```text
(x, y, heading)
```

During an update:

1. each particle moves according to the estimated robot motion,
2. expected field measurements are compared with the real LiDAR scan,
3. particles that better match the scan receive higher weight,
4. unlikely particles are removed,
5. high-probability particles are resampled.

Conceptually:

```text
Initial hypotheses
. . . . . . . . . . .
. . . . . . . . . . .

        ↓ motion
        ↓ scan comparison
        ↓ weighting
        ↓ resampling

     . . .
      ...
       .
       ↓

Converged robot pose
```

The particle cloud normally converges around the real position after the system receives enough useful measurements.

---

### 6.2.1 Localization Visualization

| Particles Scattered | Particles Converged |
|:---:|:---:|
| Point Cloud scattered | Point Cloud converged |

---

## 6.3 Field Map

`field_map.py` represents the known WRO geometry mathematically.

The map contains information such as:

- outer walls,
- centre block,
- legal start areas,
- and field boundaries.

The localizer can therefore evaluate whether a hypothetical pose agrees with the measured LiDAR scan.

---

## 6.4 Heading Fusion

The IMU provides a coarse orientation reference. LiDAR wall geometry provides a more precise orientation modulo the repeated 90° field geometry. The two sources are therefore combined to improve the robot’s overall orientation estimate.

The current implementation follows this concept:

```python
def _resolve_heading(self, scan):
    coarse = self.field_heading()
    fine, quality = self.scan_orientation(scan)

    if fine is None:
        return coarse

    delta = (angle_difference(fine, coarse) + 45.0) % 90.0 - 45.0

    return normalize_angle(coarse + delta)
```

The idea is:

```text
IMU
→ Which field quadrant are we facing?

LiDAR
→ Precise wall orientation inside that quadrant
```

Neither source alone provides exactly the same information.

---

## 6.5 Why the IMU Is Not Used as the Only Heading Source

The BNO055 is initialized relative to the robot's starting direction rather than relying on a fully calibrated geographic heading.

IMU measurements can also experience:

- drift,
- magnetic interference,
- and absolute-heading uncertainty.

The field geometry visible in the LiDAR therefore provides an additional heading reference.

---

## 6.6 Pose Confidence

Localization produces a confidence value between:

```text
0.0 and 1.0
```

The current documented threshold for a sufficiently trustworthy pose is approximately:

```text
0.35
```

Downstream behavior checks this confidence before making decisions that depend strongly on absolute field position.

This is important because:

> **A wrong position estimate that looks valid can be more dangerous than explicitly recognizing that the robot is temporarily uncertain.**

---

## 6.7 Motion Model

During the normal racing loop, the Raspberry Pi reports estimated movement to the localizer.

An important current limitation is:

> **The high-level Raspberry Pi localization does not yet use returned encoder counts as its primary odometry input.**

The Arduino already reads the encoder and can use it for finite distance-based movements. However, the Raspberry Pi path-following motion model currently estimates movement from commanded driving behavior. Integrating encoder telemetry directly into localization remains a future improvement.

---

## 6.8 Localization Pipeline

```text
Previous Pose
     |
Motor Motion Estimate
     |
     v
Particle Motion Update
     |
     +--------------------+
     |                    |
     v                    v
LiDAR Scan             Field Map
     |                    |
     +---------+----------+
               |
               v
          Scan Scoring
               |
               v
         Particle Weights
               |
               v
           Resampling
               |
               +---------- IMU Heading
               |
               v
      Pose + Confidence
```

---

# 7. Path Generation and Track Following

Once the robot knows approximately where it is, it needs a target path. The final system generates a complete loop before driving. This path is called the **racing line**.

---

## 7.1 Racing Line

The racing line is a rounded closed path positioned between the outer field wall, and the central block.

It is stored in two useful forms:

### 7.1.1 Mathematical geometry

Allows the software to evaluate properties such as:

- path curvature,
- distance along the path,
- and future path direction.

### 7.1.2 Sampled points

The path is also sampled approximately every:

```text
20 mm
```

This allows efficient calculations such as:

> How far along the lap is the robot?

---

## 7.2 Starting Direction

The robot does not require the blue or orange track line to determine its driving direction. During setup, the navigation system can select the path direction requiring the smaller initial rotation. This limits the required initial path alignment.

The intended result is that the initial heading difference is no greater than approximately:

```text
90°
```

---

## 7.3 Why Pure Pursuit?

The final path-following system uses Pure Pursuit instead of a steering PID based only on the robot’s offset from the wall. Pure Pursuit is a geometric path-tracking algorithm.

It asks:

> If the robot is here and the target path is there, what circular arc would connect the vehicle toward a point further ahead on that path?

Pure Pursuit geometry

The main calculation is approximately:

```python
curvature = 2.0 * math.sin(math.radians(alpha)) / distance

road_wheel = math.degrees(
    math.atan(self.wheelbase_mm * curvature)
)

command = (
    road_wheel
    / self.max_road_wheel_deg
    * self.max_steer_command
)
```

Where:

- `alpha` is the angular difference to the lookahead target,
- `distance` is the distance to the target point,
- `wheelbase_mm` represents vehicle geometry,
- `road_wheel` is the required physical wheel angle.

---

## 7.4 Why Not Use Only a Wall-Offset PID?

A wall-following PID can be effective when the goal is simply to maintain a fixed distance from one wall.

Our final software already contains a geometric representation of:

- robot pose,
- field geometry,
- desired path,
- obstacle positions.

Pure Pursuit allows these components to work together within the same coordinate system. The controller therefore follows an explicit planned path instead of only reacting to the latest side-distance error. However, we do not claim that Pure Pursuit was experimentally proven to be better than every possible PID controller.

The choice was primarily architectural:

> Once a reliable field pose and target path existed, a geometric path-following algorithm matched the structure of the problem directly.

---

## 7.5 Lookahead Distance

Pure Pursuit depends heavily on the **lookahead distance**.

### Short Lookahead

Advantages:

- tighter tracking,
- faster response to path curvature.

Disadvantages:

- more sensitive to localization noise,
- more likely to oscillate at higher speed.

### Long Lookahead

Advantages:

- smoother steering,
- greater stability.

Disadvantages:

- increased corner cutting,
- slower correction to path deviation.

The software therefore scales lookahead with driving speed.

Pure Pursuit result

---

## 7.6 Steering Rate Limiting

Even if a calculated steering target changes instantly, the physical servo cannot. The control system therefore limits how quickly the steering command can change. This is important because the measured steering actuator has non-zero response time.

A software controller that assumes instantaneous steering can produce:

- oscillation,
- overshoot,
- or unrealistic commands.

---

## 7.7 Speed Selection

The path controller does not always use one fixed motor command.

Speed selection can consider several limits, such as:

- cornering requirement,
- localization uncertainty,
- and LiDAR clearance.

Conceptually:

```text
Corner-Speed Limit
        |
Lost-Pose Speed Limit
        |
LiDAR Clearance Limit
        |
        v
Choose Safest / Lowest Required Speed
```

This allows driving behavior to become more conservative when the environmental or localization condition is less reliable.

---

# 8. Obstacle Detection and Traffic-Pillar Strategy

The Obstacle Challenge requires the robot to distinguish between:

- red traffic pillars,
- green traffic pillars.

The passing rule is:

```text
RED   → pass on its RIGHT
GREEN → pass on its LEFT
```

The final software uses the camera to identify pillar color and estimate its physical position.

---

## 8.1 Obstacle-Handling Pipeline

```text
Camera Frame
     |
     v
Color Conversion
     |
     v
HSV Threshold
     |
     v
Candidate Region
     |
     v
Bounding Rectangle
     |
     +----------> Pillar Color
     |
     +----------> Pixel Position
     |
     +----------> Apparent Height
                       |
                       v
                Distance Estimate
                       |
                       v
                 Camera Bearing
                       |
                       v
                 Robot Pose
                       |
                       v
                Field Coordinate
                       |
                       v
                   Block Map
                       |
                       v
              Racing-Line Offset
                       |
                       v
                 Pure Pursuit
```

---

## 8.2 Why HSV Instead of Raw RGB Thresholding?

Lighting intensity changes RGB values strongly. Hue provides a more useful representation for separating color from brightness. The final code therefore converts visual information to HSV and uses tuned color ranges.

Current configuration:

```python
COLOR_SPECS = {
    #                anchor RGB     hue_tol  saturation   value
    Color.GREEN:  ((70, 120, 60),        9,   (90, 230),  (20, 250)),
    Color.RED:    ((140, 30, 30),        6,  (125, 210),  (55, 200)),
}
```

The values are tuned using:

```text
test_color_picker.py
```

rather than selecting thresholds only from theoretical colors.

---

## 8.3 Distance from Apparent Pillar Height

The traffic pillars have a known physical height.

The current software uses:

```text
BOX_HEIGHT_CM = 10.0
```

The apparent pixel height can therefore be converted to an angular height and then to an estimated distance.

Current implementation concept:

```python
BOX_HEIGHT_CM = 10.0

DEG_PER_PX = (
    CAPTURED_HORIZONTAL_FOV_DEG
    / CAPTURED_FRAME_WIDTH_PX
)

angular_height_deg = max(rect[1]) * DEG_PER_PX

distance_cm = (
    (BOX_HEIGHT_CM / 2.0)
    / math.tan(math.radians(angular_height_deg / 2.0))
)

bearing_deg = self._horizontal_pixel_to_angle(center_x)
```

### 8.3.1 Camera FOV Verification

The current software uses an approximately:

```text
80° horizontal FOV calibration value
```

for this calculation.

The software constant should be treated as a **calibration parameter**, not automatically as the manufacturer's optical specification.

---

## 8.4 Converting a Detection to Field Coordinates

A camera detection by itself is temporary.

Once the camera looks away, the image no longer contains the pillar.

The software therefore combines:

```text
Robot Pose
+
Pillar Bearing
+
Pillar Distance
```

to calculate a pillar position in field coordinates.

That position is stored in the `block_map`.

This converts:

> **a temporary camera observation**

into:

> **a persistent environmental object**

---

## 8.5 Passing Side

The current side-selection logic is:

```python
SIDE_FOR_COLOR = {
    Color.GREEN: -1.0,
    Color.RED:   +1.0
}
```

where the sign represents lateral position relative to travel direction.

Conceptually:

```text
GREEN
→ move target path to pillar's left side

RED
→ move target path to pillar's right side
```

---

## 8.6 Required Clearance

The target path is not shifted by one arbitrary constant from the center line.

The required offset accounts for:

- requested clearance,
- robot half-width,
- optional color-specific padding,
- pillar half-width.

Current concept:

```python
def _required_offset_mm(self, color):
    return (
        self.setting("blocks.clearance_mm")
        + self.setting("blocks.robot_half_width_mm")
        + self.setting(extra_key)
        + BLOCK_SIZE_MM / 2.0
    )
```

Current documented values include approximately:

```text
Base clearance       = 140 mm
Robot half-width     = 160 mm
Additional red space = 80 mm
```

---

## 8.7 Smooth Path Deformation

The racing line does not jump instantly sideways around a detected obstacle. A sudden path discontinuity would create a large steering request. The obstacle offset therefore fades in and out smoothly.

Conceptually:

```text
Normal Racing Line
───────────────╮
               ╰──────╮
                      │ Pillar
               ╭──────╯
───────────────╯
Normal Racing Line
```

The current implementation uses a smoothstep-style transition.

Documented tuning includes approximately:

```text
Begin offset ~600 mm before pillar
Hold / continue until ~450 mm after pillar
```

The modified path is also clamped so that avoiding a traffic pillar cannot intentionally push the robot beyond the available corridor.

Obstacle path

---

## 8.8 Why Bend the Existing Racing Line?

An alternative architecture would be:

```text
Normal Driving Controller
        ↓ obstacle
Switch Controller
        ↓
Obstacle Avoidance Controller
        ↓
Switch Back
        ↓
Normal Controller
```

Our final architecture instead uses:

```text
Normal Racing Line
        ↓ obstacle
Modify Racing Line
        ↓
Same Pure Pursuit Controller
```

Advantages include:

- one steering-controller architecture,
- smoother transition into obstacle passing,
- less duplicated steering logic,
- easier reasoning about path behavior.

The trade-off is that obstacle position must be estimated accurately enough to modify the path in field coordinates.

---

## 8.9 Obstacle Edge Cases

The software includes explicit checks for unreliable detections.

### Low-confidence robot pose

If the robot's own pose is unreliable, the system should not place a camera detection into the permanent block map.

Reason:

> A pillar stored at the wrong field location can remain believable after the original bad camera frame has disappeared.

### Detection inside a field wall

If the transformed detection appears inside known wall geometry, it is rejected.

This can occur because of:

- reflections,
- inaccurate range estimate,
- incorrect pose,
- or false visual detection.

### LiDAR reports blocked path while camera reports no pillar

The LiDAR clearance information is treated as the higher-priority safety signal.

Camera absence is not proof that physical space is clear.

---

# 9. Parking Strategy

The current parking strategy uses a fixed, multi-step maneuver. The original software documentation identifies **four main parking steps**.

---

## 9.1 High-Level Parking Sequence

```text
PHASE 1
Position Robot
and Align Rear
      |
      v
PHASE 2
Turn + Reverse
into Parking Area
      |
      v
PHASE 3
Reverse Straight
      |
      v
PHASE 4
Final Reverse Turn
until Parallel
      |
      v
STOP
```

---

### Phase 1 — Initial Positioning

The robot moves to a position where the rear section is appropriately aligned with the parking area.

### Phase 2 — Reverse Entry

The steering is turned and the vehicle reverses into the parking space.

### Phase 3 — Straight Reverse

The steering is adjusted and the robot continues backwards.

### Phase 4 — Final Alignment

A final steering correction is performed while reversing so that the robot ends approximately parallel with the outer field wall.

---

# 10. Sensor Fusion and Information Arbitration

The robot uses several sensors, but it does not treat all measurements as equally appropriate for every task.

---

## 10.1 Sensor Responsibilities

| Sensor / Source | Trusted For | Not Primarily Used For |
|---|---|---|
| **RPLiDAR C1** | Position, wall geometry, precise field orientation, clearance | Pillar color |
| **BNO055 IMU** | Relative heading / field quadrant | Absolute position |
| **Camera** | Pillar color, bearing, apparent-size distance | Wall localization |
| **Motor command / motion model** | Estimated motion between localization updates | Absolute position |
| **Encoder** | Arduino-side motor rotation / finite-distance movement | Currently not primary Pi localization odometry |

---

## 10.2 Fused Heading

Heading is one genuinely fused quantity.

```text
IMU
   |
   | coarse direction / quadrant
   v
Heading Fusion
   ^
   | precise wall orientation
   |
LiDAR
```

The IMU provides the large-scale orientation reference, while LiDAR geometry refines it relative to the rectangular field.

---

## 10.3 Fused Traffic-Pillar Position

The other major fused result is the persistent block map.

```text
Camera
→ Color + Bearing + Range

Robot Localization
→ x + y + heading

Combined
→ Pillar field coordinate
```

Without the current robot pose, a camera detection is only a location relative to the camera. Combining the detection with localization allows the obstacle to become part of the field model.

---

## 10.4 When Sensors Disagree

The software uses explicit arbitration rules.

### Geometry

**LiDAR / field geometry wins.**

If the robot pose is not reliable enough, a camera detection is not inserted into the block map.

### Heading

The disagreement between LiDAR orientation and the IMU reference is folded into the expected 90° field symmetry.

### Camera says clear, LiDAR says blocked

**LiDAR wins.**

A missing camera detection does not prove that physical space is clear.

### Detection falls inside wall geometry

The detection is discarded.

---

## 10.5 Sensor-Fusion Visualization

Sensor Fusion

---

# 11. Edge Cases, Safety and Failure Handling

## 11.1 Software Failure / Exception

```text
Unexpected Python Error
        |
        v
finally:
    finish()
        |
        v
Stop Motor
Center Steering
```

This prevents an exception from intentionally leaving the vehicle driving with the previous command.

---

## 11.2 Competition Timeout

If the task exceeds the configured:

```text
180 s
```

the loop exits and performs normal cleanup.

---

## 11.3 Low Localization Confidence

When localization confidence decreases, the path-driving system can switch to more conservative behavior. The software monitors whether the robot is effectively “lost” instead of assuming that every pose estimate is reliable. The exact speed response depends on the system configuration.

---

## 11.4 Invalid Pillar Position

If a pillar is detected while the robot's own position is unreliable:

```text
Bad Pose
+
Camera Detection
=
Do Not Store Detection
```

This avoids contaminating the persistent map with incorrect world coordinates.

---

## 11.5 Pillar Position Inside Wall

```text
Detected Pillar
      |
Transform to Field
      |
      v
Inside Known Wall?
   /        \
 Yes        No
  |          |
Drop       Store
```

---

## 11.6 Insufficient Obstacle Corridor

The current final-round configuration performs a startup feasibility check. The existing documentation notes that, under one configuration, a pillar placed directly on the racing line could require an offset greater than the available corridor. This condition is intentionally detected rather than being silently ignored.

---

## 11.7 IMU Unavailable

The navigation architecture is not intended to depend on one sensor alone.

---

## 11.8 LiDAR Unavailable

LiDAR is central to the localization architecture.

If LiDAR initialization fails, the robot cannot provide normal field localization.

---

## 11.9 Camera Unavailable

The Open Challenge does not require traffic-pillar color recognition in the same way as the Obstacle Challenge.

The final Obstacle Challenge behavior, however, depends on camera detection.

---

# 12. Testing, Simulation and Tuning

Testing is a central part of the software architecture.

The most important development tool this season is not physically mounted on the robot:

> **A simulation and test environment that runs the real navigation code without requiring the physical track for every change.**

---

## 12.1 Testing Without the Robot

Several scripts execute the real navigation modules against a simulated robot.

Examples:

```bash
uv run python test_navigation.py
```

Purpose:

- visualize localization convergence,
- test particle behavior,
- verify field geometry.

---

```bash
uv run python test_driving.py --trials 24
```

Purpose:

- run repeated driving trials,
- randomize starting placement,
- report pass / fail behavior,
- evaluate minimum clearance.

---

```bash
uv run python test_steering.py --sweep speed.corner 40,50,60,70
```

Purpose:

- compare parameter values,
- evaluate trade-offs,
- produce tuning tables.

---

## 12.2 Why Use Simulation?

Physical WRO track testing requires:

- full robot preparation,
- battery preparation,
- field setup,
- manual reset,
- observation,
- and significant time.

Simulation allows clearly incorrect configurations to be rejected before physical testing.

However, simulation cannot perfectly reproduce:

- glare,
- shadows,
- camera exposure,
- floor friction,
- wheel slip,
- dust,
- battery sag,
- cable movement,
- or mechanical wear.

Therefore:

> **Simulation reduces wasted track time; it does not replace real-world validation.**

---

## 12.3 Simulated Steering Lag

A simulator with instantaneous steering would make the controller appear unrealistically stable. The simulator therefore includes steering lag.

This helps reproduce the weaving behavior that can occur when:

```text
Controller Request
changes faster than
Physical Servo Response
```

---

## 12.4 Steering Calibration

Two steering characteristics cannot be reliably obtained only from the nominal servo command.

They must be measured on the real vehicle.

## 12.4.1 Maximum Steering Geometry

The steering-calibration tool drives arcs and estimates the real turning geometry.

Testing found that the actual robot turned approximately:

> **21% more than the original 40° full-lock assumption.**

This is important because Pure Pursuit converts required curvature into a physical steering model. An incorrect maximum steering assumption produces an incorrect command scale.

### 12.4.2 Steering Response Time

The steering-response tool measured approximately:

> **0.35 s to reach 63% of the steering response.**

This demonstrates that the actuator cannot be modeled as instantaneous. The software therefore accounts for physical steering behavior rather than treating the servo as an ideal mathematical device.

---

## 12.5 Why Integrate Steering Measurements Over a Run?

The `SteeringCalibrator` can estimate steering geometry during a normal lap.

It does not simply compare:

```text
Command at time t
vs.
Wheel behavior at time t
```

because the steering mechanism has delay.

The physical response belongs to an earlier command. Integrating the motion over a longer interval avoids directly comparing a cause with an effect that has not yet occurred.

---

## 12.6 Debug Visualization

The robot exposes several debugging tools.

### Status Output

A status line can include:

- elapsed time
- lap progress
- position
- path offset
- steering
- wheel angle
- speed
- localization confidence

Example:

```text
[ 12.4s] lap 0.87/3  (+102.4,-140.1)cm
off-line +1.2cm
steer=-8.3
wheel=-4.5deg
speed=70
conf=0.78
```

### 12.6.1 `--debug`

Displays a live top-down visualization containing:

- field
- particle cloud
- LiDAR points
- racing line
- obstacle-modified path
- robot pose
- Pure Pursuit target point

### 12.6.2 `--ascii`

Provides debugging information in a terminal-only environment such as SSH.

### 12.6.3 Object-Detection Debugging

The object solver provides visual debugging for:

- camera frame
- traffic-pillar bounding boxes
- detected color
- estimated position
- top-down radar visualization

### 12.6.4 Color Picker

```text
test_color_picker.py
```

allows a team member to select a real camera pixel and inspect its:

- RGB value,
- HSV value.

This makes threshold tuning traceable to real competition images.
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

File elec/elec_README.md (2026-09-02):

# Electrical, Power & Sensor Architecture

This document describes the complete electrical and sensing architecture of the **YBR-SUNFLOWER WRO 2026 Future Engineers robot**, including the power system, controllers, communication interfaces, sensors, physical sensor placement, wiring, calibration and initialization methods, development iterations, failure modes, reliability decisions, and final electrical configuration.

The purpose of this document is not only to identify the components used in the robot, but also to explain why each electrical and sensing component was selected, how power is generated, regulated, and distributed, how current demand influenced the power architecture, why different sensors are used for different types of information, why each sensor is placed in its final physical position, how the sensors are calibrated or initialized, what electrical and sensing problems were discovered during development, how testing changed the final architecture, what failure modes were considered,
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

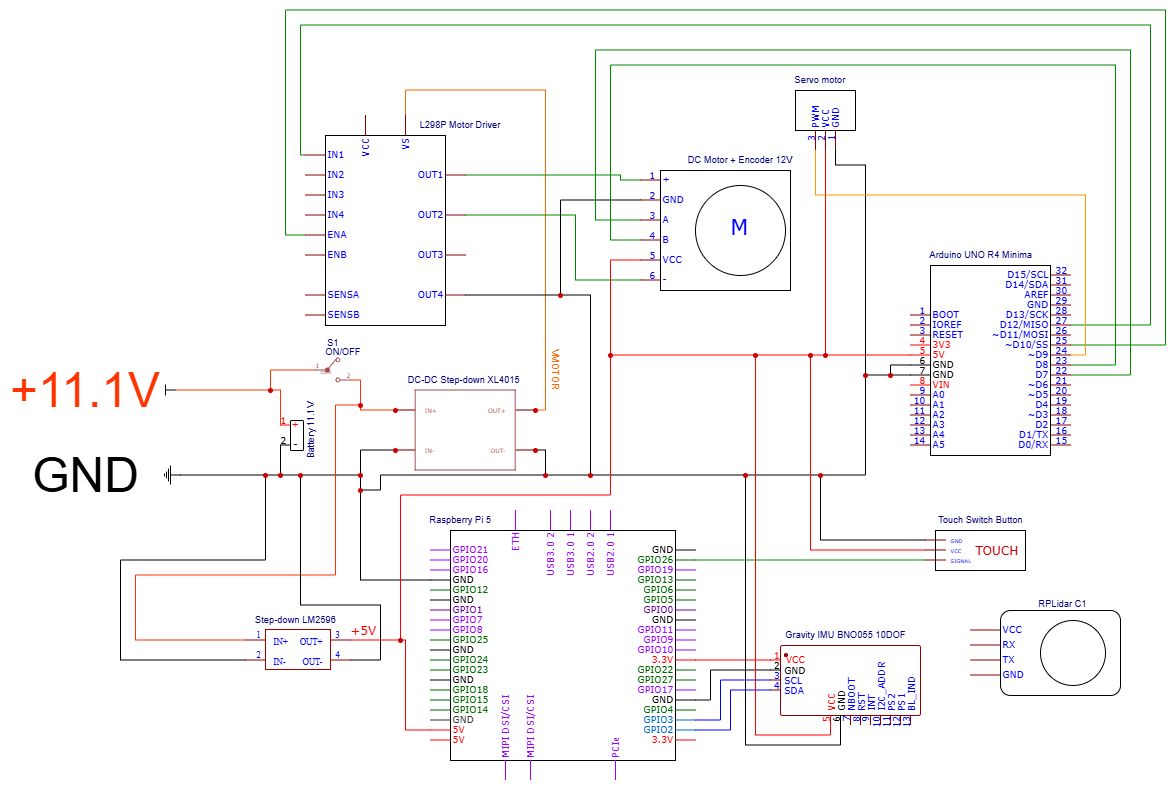
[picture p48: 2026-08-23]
schemes/Schematic Diagram.png

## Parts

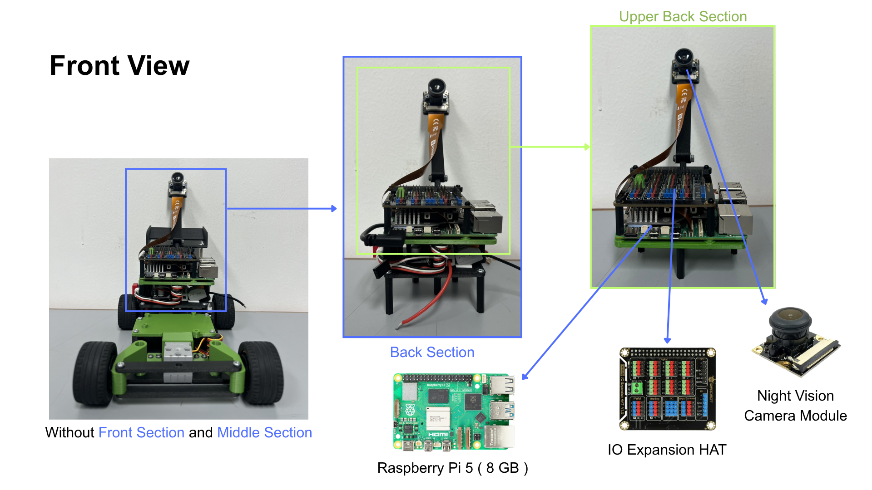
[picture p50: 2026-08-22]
other/ComponentsImage4.png

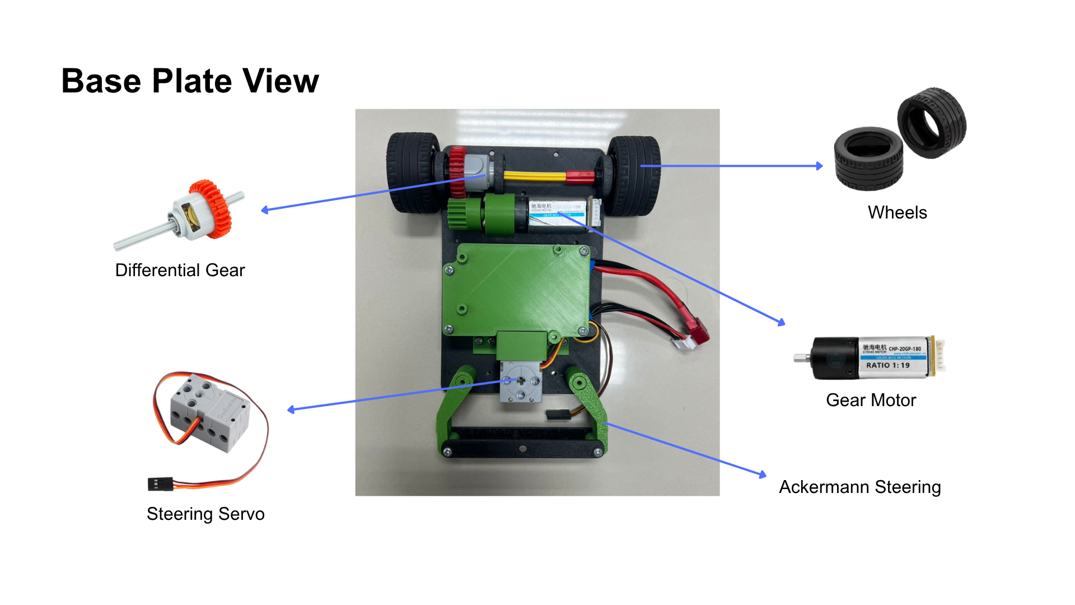
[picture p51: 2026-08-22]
other/ComponentsImage1.png

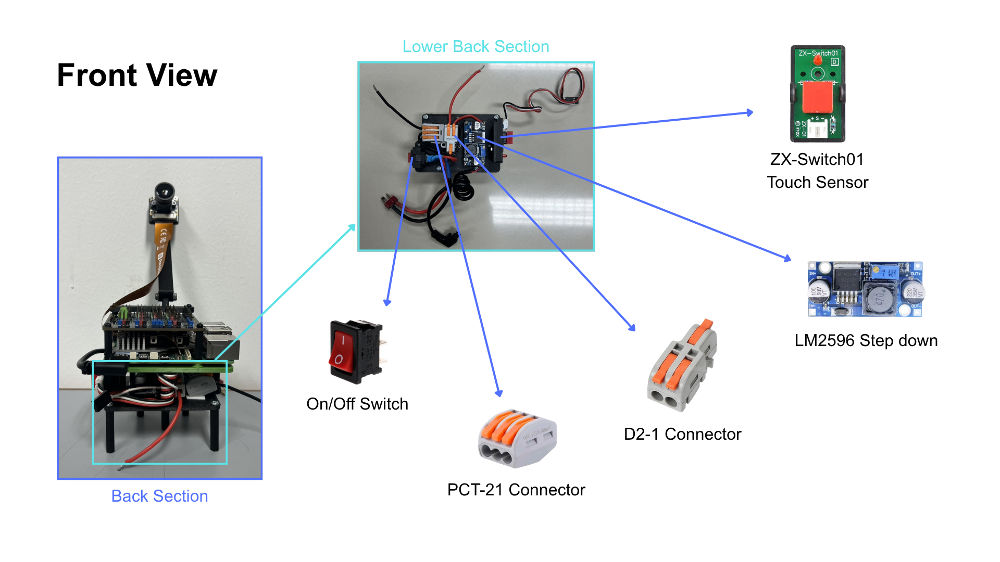
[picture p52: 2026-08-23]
other/ComponentsImage5.png

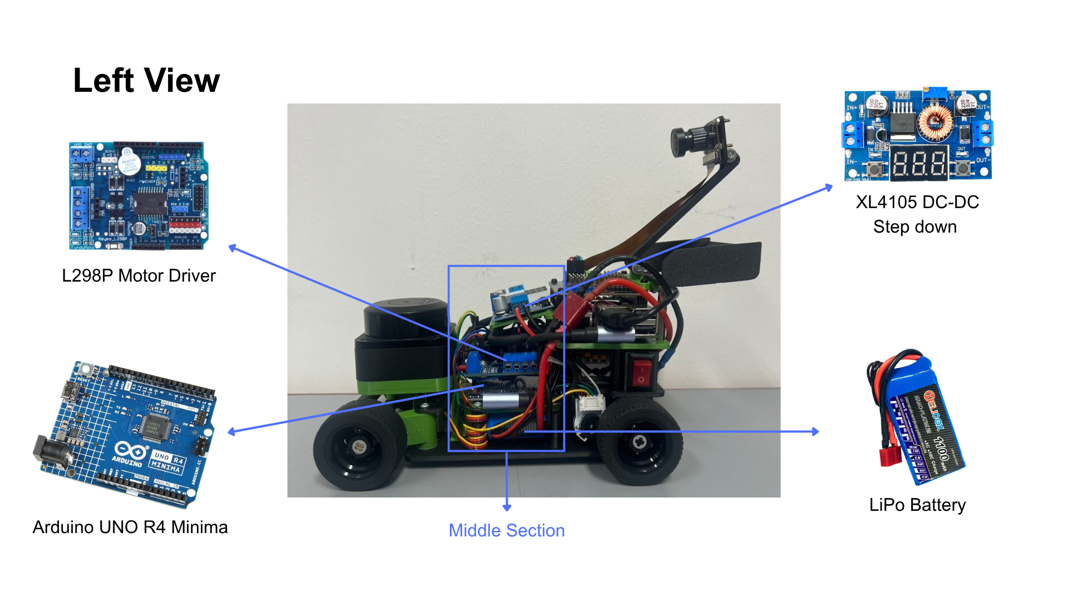
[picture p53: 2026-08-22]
other/ComponentsImage3.png

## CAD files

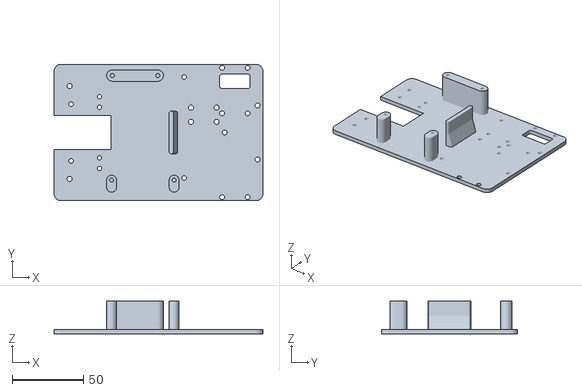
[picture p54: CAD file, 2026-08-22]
mech/models/MainBase.stl
147.0 x 96.0 x 23.0

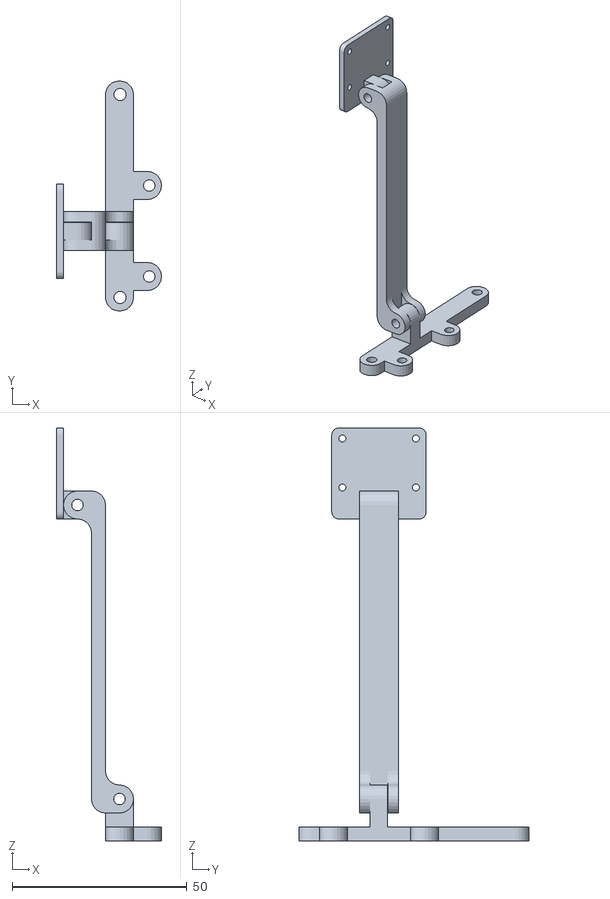
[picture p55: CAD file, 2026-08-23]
mech/models/CamMount.stl
30.0 x 65.7 x 118.0

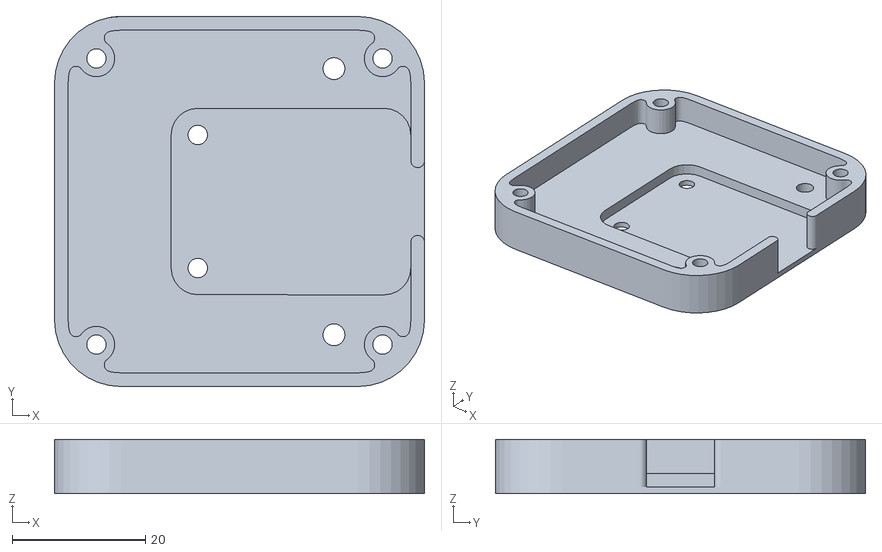
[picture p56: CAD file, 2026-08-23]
mech/models/LiDARMount.stl
55.6 x 55.6 x 8.16

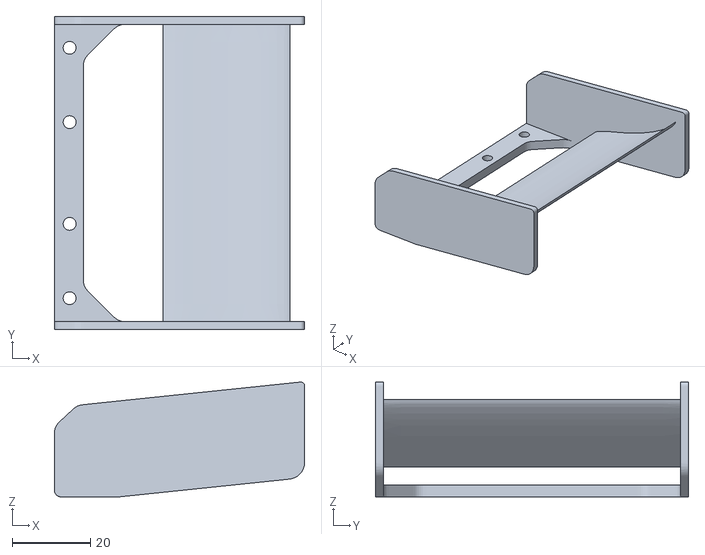
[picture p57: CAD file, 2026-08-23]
mech/models/RearWing.stl
64.0 x 80.0 x 29.4

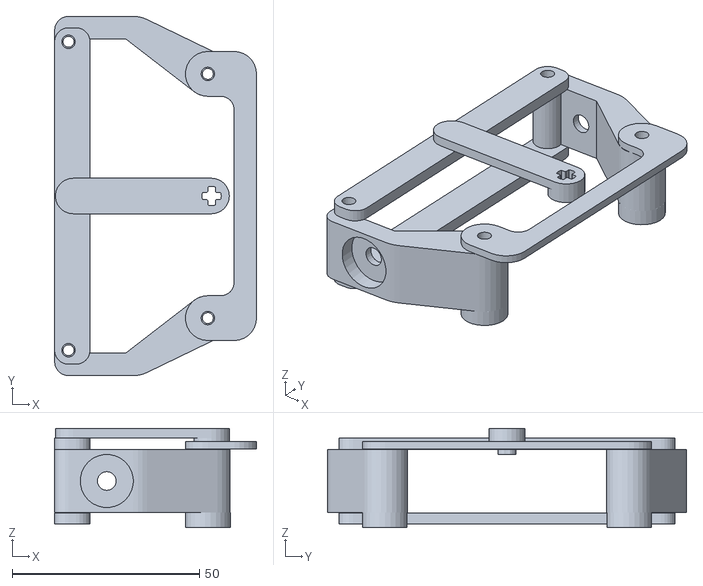
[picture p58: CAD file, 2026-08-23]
mech/models/SteeringSystem.stl
54.0 x 96.0 x 26.5

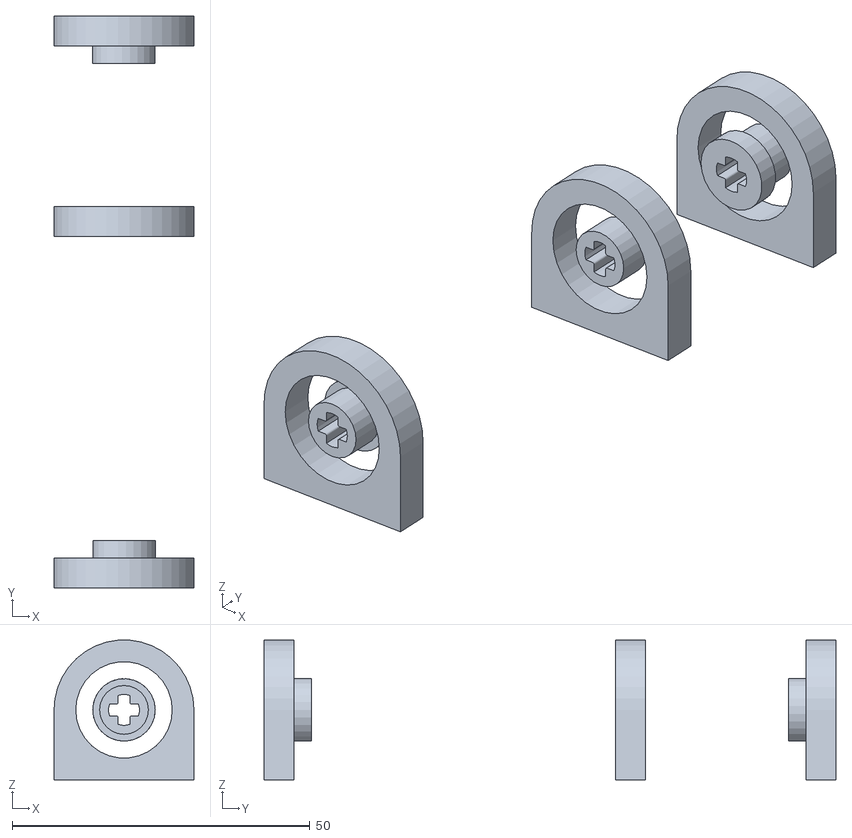
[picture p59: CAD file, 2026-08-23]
mech/models/BearingSystem.stl
23.5 x 96.0 x 23.5

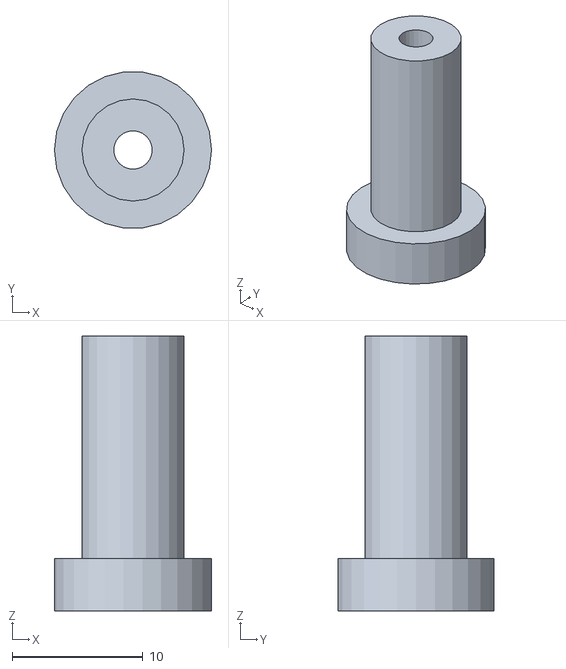
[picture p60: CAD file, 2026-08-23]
mech/models/SteeringAxle.stl
12.0 x 11.9 x 21.0

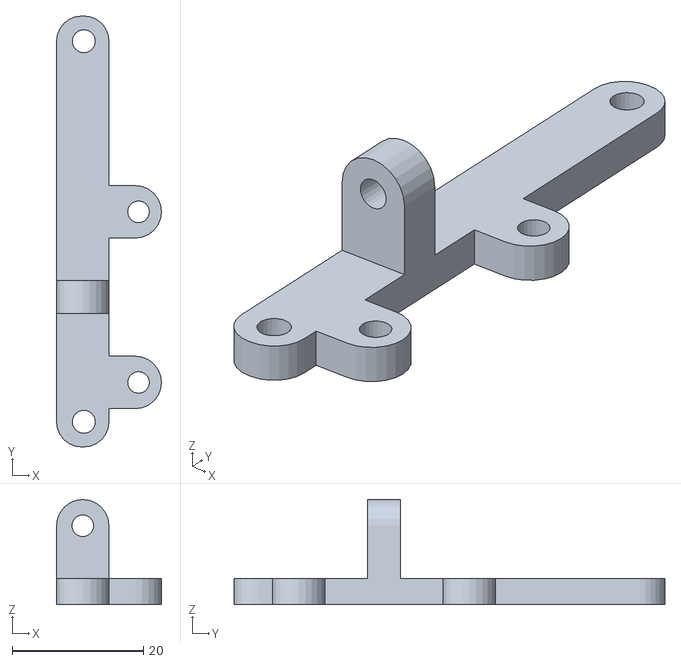
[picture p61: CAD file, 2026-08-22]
mech/models/CamArmConnector.stl
16.0 x 65.7 x 16.0

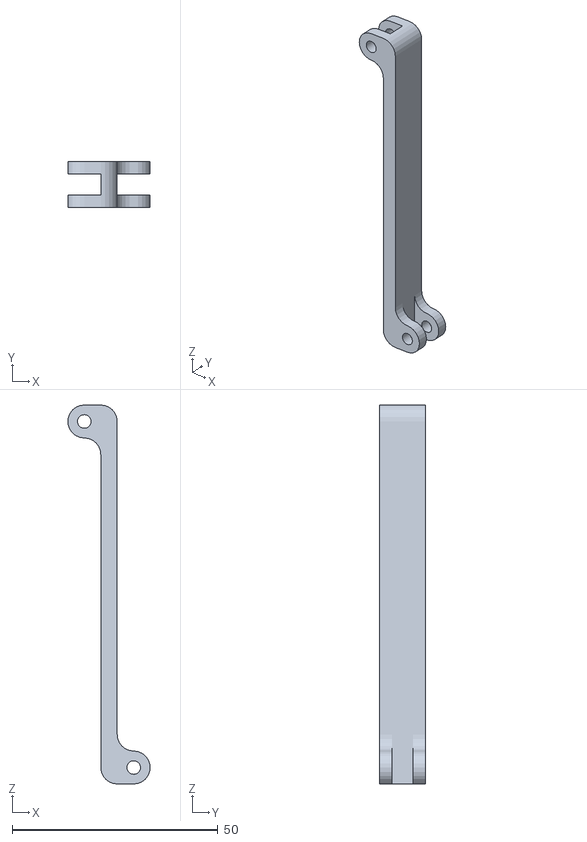
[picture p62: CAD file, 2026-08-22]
mech/models/CamArm.stl
20.0 x 11.2 x 92.0

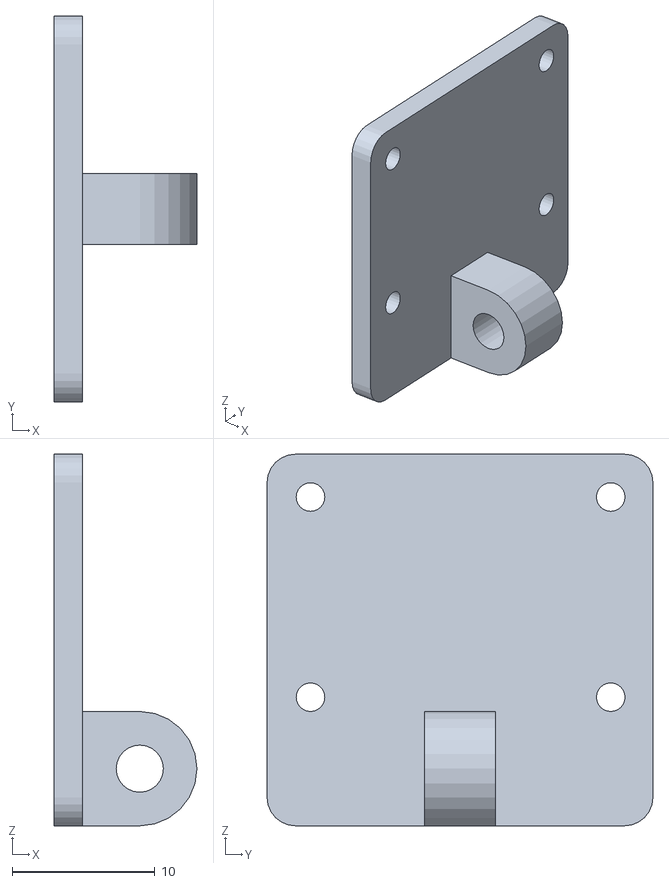
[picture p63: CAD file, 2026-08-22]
mech/models/CamPlate.stl
10.0 x 27.0 x 26.0

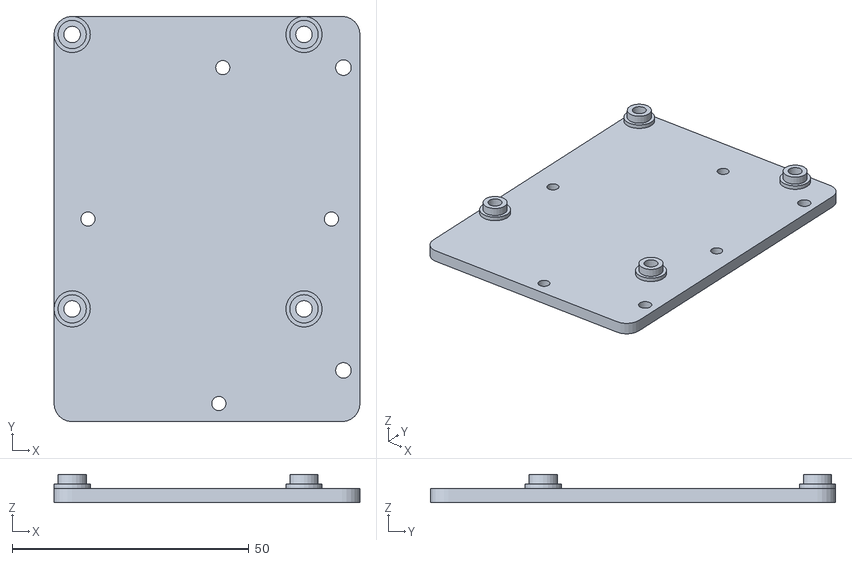
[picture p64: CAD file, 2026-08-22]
mech/models/PiPlate.stl
64.7 x 85.7 x 6.00

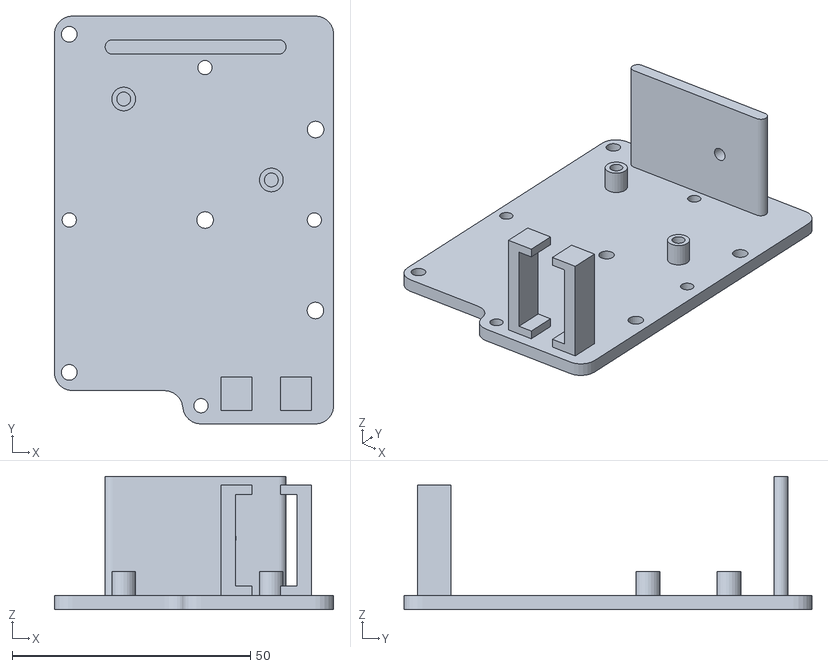
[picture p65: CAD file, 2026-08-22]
mech/models/ElecPlate.stl
58.7 x 85.7 x 28.0

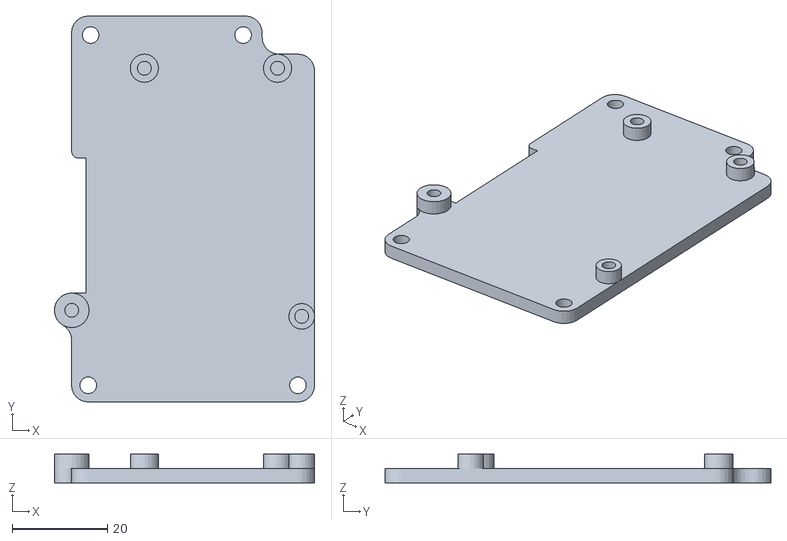
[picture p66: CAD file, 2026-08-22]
mech/models/UnoPlate.stl
54.6 x 81.0 x 6.00

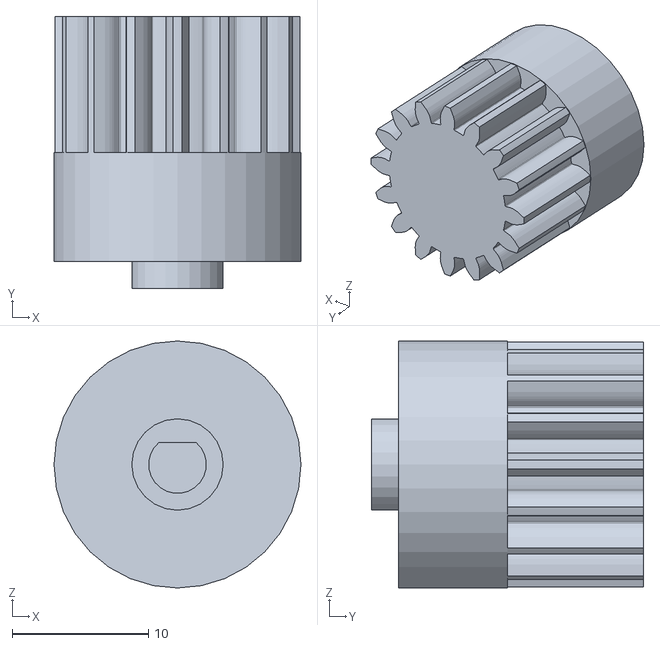
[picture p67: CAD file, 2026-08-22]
mech/models/GearAdapter.stl
18.2 x 20.0 x 18.2

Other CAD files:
mech/models/R_SteeringArm.stl
mech/models/Mid_AxleSleeve.stl
mech/models/Top_SteeringMount.stl
mech/models/Bottom_SteeringMount.stl
mech/models/BearingMount.stl
mech/models/L&R_AxleSleeve.stl
mech/models/L_SteeringArm.stl
mech/models/MotorBracket.stl
mech/models/ServoBracket.stl
mech/models/SteeringLinkageArm.stl
mech/models/StepdownTray.stl
mech/models/Top_SteeringCap.stl

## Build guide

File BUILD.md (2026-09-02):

# Build & Reproduction Guide

This document is the complete reproduction guide for the **YBR-SUNFLOWER WRO 2026 Future Engineers robot**.

Its purpose is different from the subsystem engineering documentation.

The subsystem documents explain **why** the robot was designed as it is:

- [`mech/mech_README.md`](mech/mech_README.md) — mechanical design and mobility
- [`elec/elec_README.md`](elec/elec_README.md) — power, electrical and sensor architecture
- [`software/software_README.md`](software/software_README.md) — software and autonomous navigation

This document explains **how to reproduce the final robot**.

A successful reproduction should be able to:

1. manufacture the mechanical parts,
2. assemble the drivetrain and steering system,
3. install the electronics and sensors,
4. reproduce the electrical wiring,
5. configure the Raspberry Pi and Arduino,
6. install the exact software dependencies,
7. verify every subsystem individually,
8. run the autonomous software,
9. and reproduce the final competition configuration.

---

# Contents

1. [Reproduction Overview](#1-reproduction-overview)
2. [Before You Start](#2-before-you-start)
3. [Bill of Materials](#3-bill-of-materials)
4. [Tools and Manufacturing Equipment](#4-tools-and-manufacturing-equipment)
5. [3D Printing and Mechanical Preparation](#5-3d-printing-and-mechanical-preparation)
6. [Mechanical Assembly](#6-mechanical-assembly)
7. [Electrical Assembly and Wiring](#7-electrical-assembly-and-wiring)
8. [Electrical Pre-Power Verification](#8-electrical-pre-power-verification)
9. [Raspberry Pi Software Setup](#9-raspberry-pi-software-setup)
10. [Arduino Setup and Firmware Upload](#10-arduino-setup-and-firmware-upload)
11. [Final Software Configuration](#11-final-software-configuration)
12. [Subsystem Verification](#12-subsystem-verification)
13. [First Autonomous Run](#13-first-autonomous-run)
14. [Testing Workflow](#14-testing-workflow)
15. [Troubleshooting](#15-troubleshooting)
16. [Competition Startup Procedure](#16-competition-startup-procedure)
17. [Version Lock and Competition Release](#17-version-lock-and-competition-release)
18. [Reproducibility Checklist](#18-reproducibility-checklist)
19. [Related Documentation](#19-related-documentation)

---

# 1. Reproduction Overview

The recommended reproduction order is:

```text
Obtain Components
       |
       v
Print Mechanical Parts
       |
       v
Assemble Drivetrain
       |
       v
Assemble Steering
       |
       v
Build Structural Layers
       |
       v
Mount Electronics
       |
       v
Complete Power Wiring
       |
       v
Verify Converter Voltages
       |
       v
Complete Signal Wiring
       |
       v
Install Raspberry Pi Software
       |
       v
Upload Arduino Firmware
       |
       v
Verify Individual Subsystems
       |
       v
Perform Low-Speed Test
       |
       v
Run Localization Test
       |
       v
Run Competition Software
```

Do not connect sensitive electronics to an unverified power converter.

The recommended workflow is:

> **Assemble → Inspect → Measure → Connect → Test**

rather than powering the complete robot immediately after wiring.

---

## 1.1 Reproduction Evidence Map

| Reproduction Requirement | Primary Resource |
|---|---|
| Mechanical design | [`mech/mech_README.md`](mech/mech_README.md) |
| CAD / STL files | [`mech/models/`](mech/models/) |
| Mechanical assembly | This document — Sections 5–6 |
| Electrical architecture | [`elec/elec_README.md`](elec/elec_README.md) |
| Schematic | [`schemes/Schematic Diagram.png`](schemes/Schematic%20Diagram.png) |
| Physical wiring | [`schemes/Wiring Diagram.png`](schemes/Wiring%20Diagram.png) |
| Electrical assembly | This document — Sections 7–8 |
| Raspberry Pi software | [`src/Raspberrypi/`](src/Raspberrypi/) |
| Arduino firmware | [`src/Arduino/Main.ino`](src/Arduino/Main.ino) |
| Software architecture | [`software/software_README.md`](software/software_README.md) |
| Testing workflow | Section 14 |
| Competition version | GitHub Release / tag |

---

# 2. Before You Start

## 2.1 Required Skills

The build requires basic experience with:

- FDM 3D printing,
- mechanical assembly,
- soldering,
- crimping / wire preparation,
- multimeter use,
- Raspberry Pi OS,
- Linux terminal commands,
- Arduino IDE,
- and basic Git usage.

---

## 2.2 Important Safety Notes

### LiPo Battery

A 3S LiPo battery can supply high current.

Before wiring:

- inspect the battery for swelling or damage,
- avoid short circuits,
- check polarity before connection,
- and disconnect the battery while modifying wiring.

### Power Converters

Always measure converter outputs with a multimeter **before connecting the Raspberry Pi, Arduino, servo, sensors, or motor electronics**.

### Mechanical Testing

During the first motor test **Lift the driven wheels off the ground.**

This prevents an incorrect motor direction or steering command from causing the robot to move unexpectedly.

---

## 2.3 Recommended Build Order

Do not start by connecting every electronic component.

Recommended sequence:

```text
Mechanical Chassis
       ↓
Drivetrain
       ↓
Steering
       ↓
Structural Layers
       ↓
Electronics Mounting
       ↓
Power Wiring
       ↓
Voltage Verification
       ↓
Signal Wiring
       ↓
Software Installation
       ↓
Subsystem Tests
       ↓
Autonomous Testing
```

---

# 3. Bill of Materials

This section lists the main components required to reproduce the final **YBR-SUNFLOWER Version 3 robot**.

Where possible, the exact model used by our team is listed together with the original purchasing link used during development.

> Some purchasing links may become unavailable over time. The important reproduction information is the component model and specification.

---

## 3.1 Main Electronic Components

| Category | Component | Qty | Notes | Purchase Link |
|---|---|---:|---|---|
| Compute | Raspberry Pi 5 | 1 | 8 GB version used by our team | [Gammaco](https://gammaco.com/gammaco/Raspberry_Pi_GB_89RD014.html)  |
| Compute | Arduino UNO R4 Minima | 1 | Standard non-Wi-Fi version | [ORtech](https://www.ortech-online.com/product/1370)  |
| Motor | CHP-20GP-180 DC geared motor with encoder | 1 | 19:1 gear ratio | [Shopee](https://th.shp.ee/dcTw6X4o)  |
| Steering | GEEKSERVO 2 kg 360° Servo | 1 | LEGO-compatible steering servo | [Shopee](https://th.shp.ee/xjXZcp6A)  |
| Sensing | RPLiDAR C1 | 1 | Main 2D environmental sensor | [DFRobot](https://www.dfrobot.com/product-2803.html)  |
| Sensing | Raspberry Pi Night Vision Camera | 1 | Used for traffic-pillar detection | [Cytron](https://th.cytron.io/p-fish-eye-lense-raspberry-pi-5mp-ir-camera)  |
| Sensing | Gravity BNO055 IMU | 1 | DFRobot SEN0253 | [DFRobot](https://www.dfrobot.com/product-1793.html)  |
| Control | L298P Motor Shield | 1 | Drive-motor control | [Shopee](https://th.shp.ee/DExzLgGb)  |
| Control | IO Expansion HAT for Raspberry Pi 5 / 4B / 3B+ | 1 | DFR0566 | [DFRobot](https://www.dfrobot.com/product-1930.html) |
| Control | ZX-Switch01 Start Button | 1 | Start Button | [INEX](https://inex.co.th/home/product/zx-switch01/)  |
| Power | Helicox 1100 mAh 11.1 V 3S LiPo | 1 | Main battery | [PrinceBot](https://www.princebotshop.com/product/%E0%B9%81%E0%B8%9A%E0%B8%95%E0%B9%80%E0%B8%95%E0%B8%AD%E0%B8%A3%E0%B9%8C%E0%B8%A3%E0%B8%B5%E0%B9%88-li-po-%E0%B8%A2%E0%B8%B5%E0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) |
| Power | LM2596 Step-Down Converter | 1 | Tune to 5.1 V | [ORtech](https://www.ortech-online.com/product/212)  |
| Power | XL4015 Step-Down Converter | 1 | Tune to 11.1 V | [ORtech](https://www.ortech-online.com/product/206)  |
| Power | Quick Wire Connectors | 2 | PCT-21 and D1-2 | [Shopee](https://th.shp.ee/pKZ9582e)  |

---

## 3.2 Mechanical Components

| Component | Qty | Notes | Purchase / File Reference |
|---|---:|---|---|
| LEGO Technic 28T Differential | 1 | Rear drivetrain | [LEGO](https://www.lego.com/en-us/product/robot-inventor-51515) |
| LEGO Tire 43.2 × 22 ZR | 4 | Final tires | [LEGO](https://www.lego.com/en-us/product/lego-mindstorms-ev3-31313) |
| LEGO Wheel Rim | 4 | Used with final tires | [LEGO](https://www.lego.com/en-us/product/lego-mindstorms-ev3-31313) |
| Front Bearings | 2 | 8x14x4mm | [Shopee](https://th.shp.ee/6UK8voGj) |
| Rear Bearings | 3 | 8x16x5mm | [Shopee](https://th.shp.ee/6UK8voGj) |
| Rear Axles | 1| LEGO Technic Axle 11 | [LEGO](https://www.lego.com/en-us/product/robot-inventor-51515) |
| Structural Pillars | 7 | M3x30 | [Shopee](https://th.shp.ee/fPzjk2dR) |
| Custom 3D-Printed Parts | 1 set | See mechanical CAD files | [`mech/models/`](mech/models/) |

---

## 3.3 Wiring and Consumables

| Item | Qty / Length | Notes | Purchase Link |
|---|---|---|---|
| Raspberry Pi ↔ Arduino USB Data Cable | 1 | USB Serial communication | [Shopee](https://th.shp.ee/pc7EZXs8) |
| RPLiDAR Adapter / USB Cable | 1 | LiDAR communication | [Shopee](https://th.shp.ee/pc7EZXs8) |
| Raspberry Pi CSI Camera Cable | 1 | Camera interface | [Cytron](https://th.cytron.io/p-fpc-22-way-to-15-way-for-camera-20cm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) |
| Power Wire | As required | Add wire gauge and approximate length |  |
| Heat-Shrink Tubing | As required | Electrical insulation |  |
| Solder | As required | Electrical assembly |  |

---

## 3.4 3D Printing Materials

| Material | Purpose | Purchase Link |
|---|---|---|
| Bambu Lab ABS | General structural and impact-tolerant parts | [Bambulab](https://asia.store.bambulab.com/products/abs-filament?id=42078846615667) |
| Bambu Lab ABS-GF | Parts requiring greater stiffness and dimensional stability | [Bambulab](https://asia.store.bambulab.com/products/abs-gf?id=41652562329715) |

The detailed reason for selecting ABS and ABS-GF is documented in:

[`mech/mech_README.md`](mech/mech_README.md)

---

# 4. Tools and Manufacturing Equipment

Recommended tools:

- FDM 3D printer
- Bambu Studio or compatible slicer
- soldering iron
- solder
- wire cutter
- wire stripper
- multimeter
- screwdrivers
- hex drivers / Allen keys
- pliers
- computer for Raspberry Pi / Arduino setup
- microSD card reader
- USB data cables

---

# 5. 3D Printing and Mechanical Preparation

The final custom mechanical parts are stored in:

[`mech/models/`](mech/models/)

The team manufactured the robot primarily using:

- Bambu Lab H2D
- ABS
- ABS-GF

Detailed material reasoning is documented in:

[`mech/mech_README.md`](mech/mech_README.md)

---

## 5.1 Final Printed-Part Preparation

Before printing:

1. identify only the **final V3 parts**,
2. inspect STL orientation,
3. select ABS or ABS-GF according to the final part configuration,
4. slice the models,
5. inspect support placement,
6. print,
7. remove supports,
8. clean mounting holes,
9. test-fit mating parts before final assembly.

---

## 5.2 Final Printed Parts

The final mechanical documentation contains the complete CAD list.

Important final components include:
- Main Base
- Electrical Base
- Arduino Base
- Raspberry Pi Base 
- Motor Bracket 
- 16T Driver Gear
- Bearing Mounts (3)
- Axle Sleeves (5)
- Steering Axles
- Steering Arms
- Steering Linkage
- Steering Mounts
- Servo Bracket 
- Camera Mount
- Camera Plate
- Camera Arm
- Camera Connector
- LiDAR / IMU Mount
- Rear Wing
- XL4015 Step-down Tray

---

## 5.3 Final Printing Settings

Only record settings that were actually used.

| Setting | ABS | ABS-GF |
|---|---|---|
| Wall loops | 4 | 4 |
| Infill | 15% | 15% |
| Support | Enable(Auto) | Enable(Auto) |
| Nozzle | 0.4mm | 0.4mm |
| Build plate | Textured PEI plate | Textured PEO plate |

---

# 6. Mechanical Assembly

The recommended mechanical assembly order is:

```text
Rear Structure
      ↓
Drivetrain
      ↓
Front Steering
      ↓
Servo
      ↓
Structural Layers
      ↓
Camera Structure
      ↓
LiDAR / IMU Structure
```

---

## 6.1 Assemble the Rear / Upper Structure

We recommend building the rear stacked section from bottom to top.

```text
Camera
   |
   v
Camera Support
   |
   v
DFR0566 / Pi Layer
   |
   v
Raspberry Pi 5
   |
   v
Electrical Base
```

Existing assembly references:

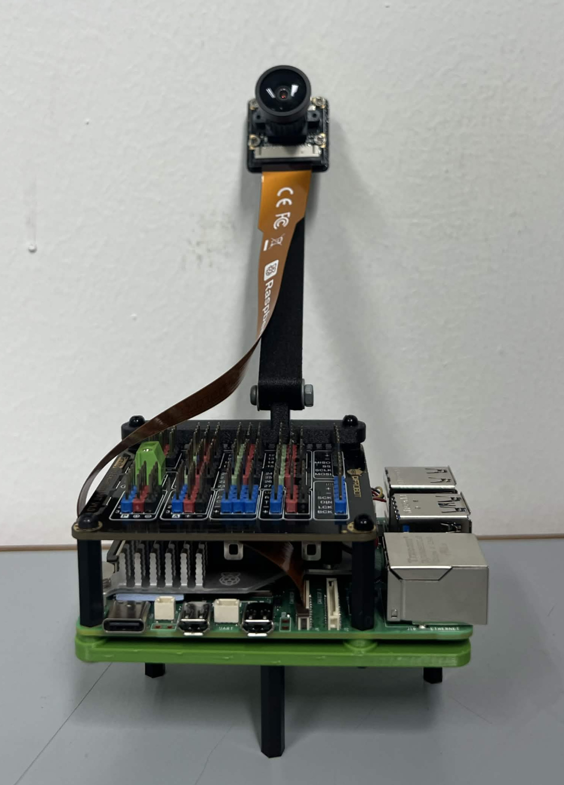
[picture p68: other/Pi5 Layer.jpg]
Pi5 Layer

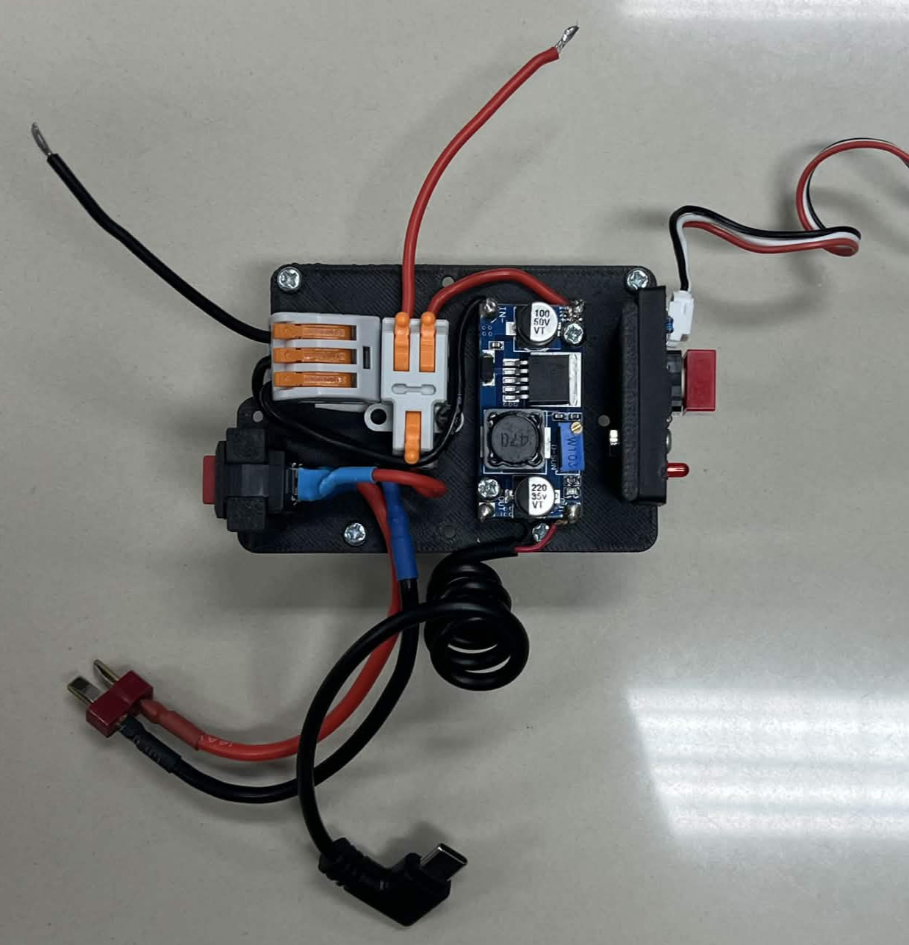
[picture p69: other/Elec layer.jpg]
Electrical Layer

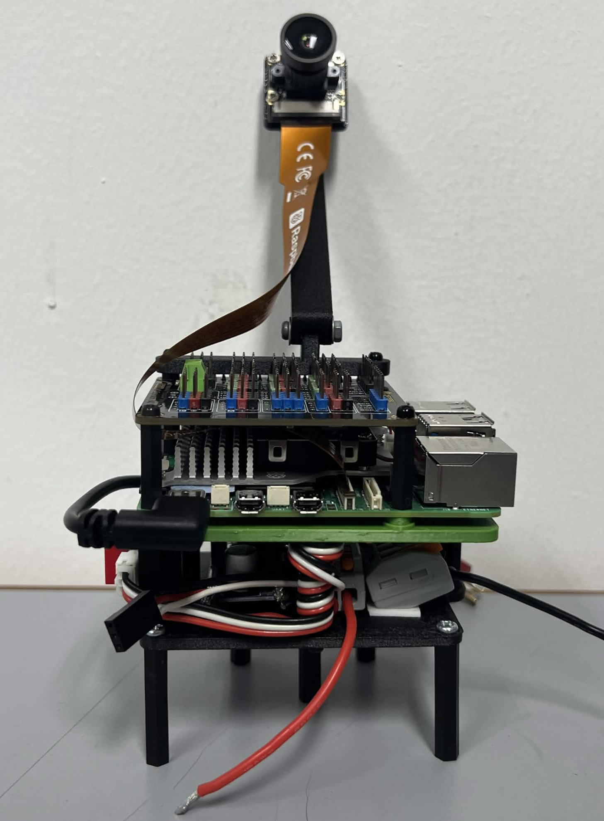
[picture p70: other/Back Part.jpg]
Back Section


Before tightening completely:

- verify the plates are parallel,
- check the pillar spacing,
- confirm cables will still be accessible.

---

## 6.2 Assemble the Rear Drivetrain

Install:

1. CHP-20GP-180 motor
2. Motor Bracket
3. 16-tooth drive gear
4. LEGO 28-tooth differential
5. rear bearings
6. axle sleeves
7. rear axles
8. wheels

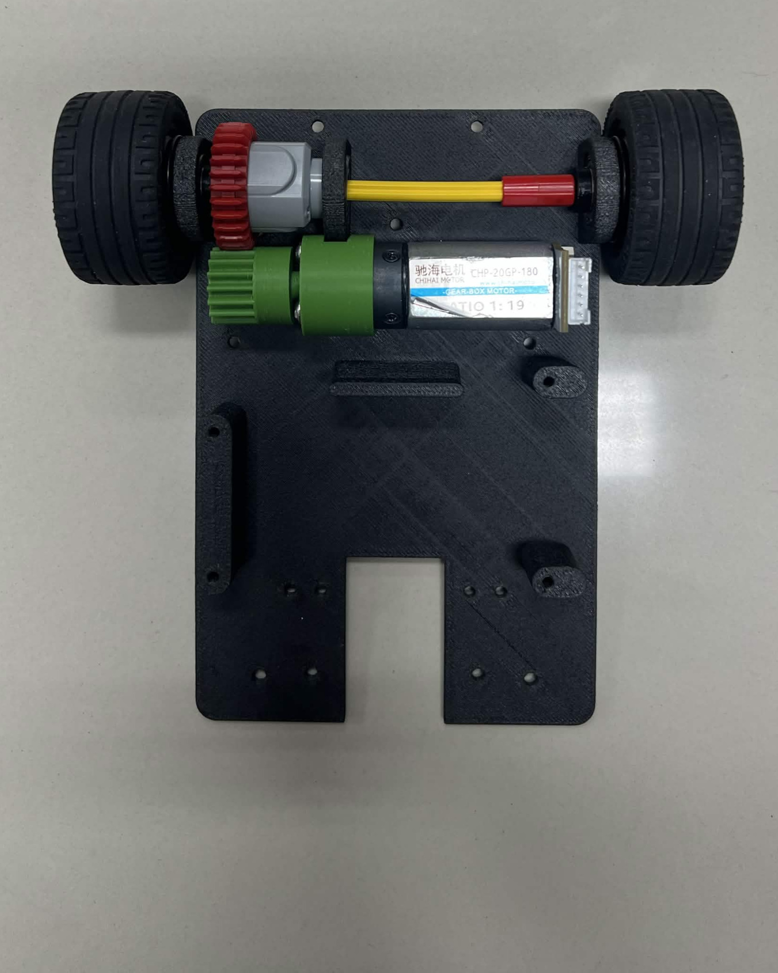
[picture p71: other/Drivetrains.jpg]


Before continuing:

- rotate the drivetrain manually,
- verify the gear teeth mesh correctly,
- confirm the differential rotates freely,
- check that the axle does not bind,
- verify both wheels rotate without excessive friction.

### Gear-Mesh Check

The 16T and 28T gears should:

- engage fully,
- rotate without skipping,
- not be forced tightly together.

Incorrect gear mesh can cause excessive current draw, increased drivetrain noise, gear wear, and reduced speed.

---

## 6.3 Install Arduino Base and Steering Servo

Mount:

- Arduino supporting plate
- steering servo
- servo bracket

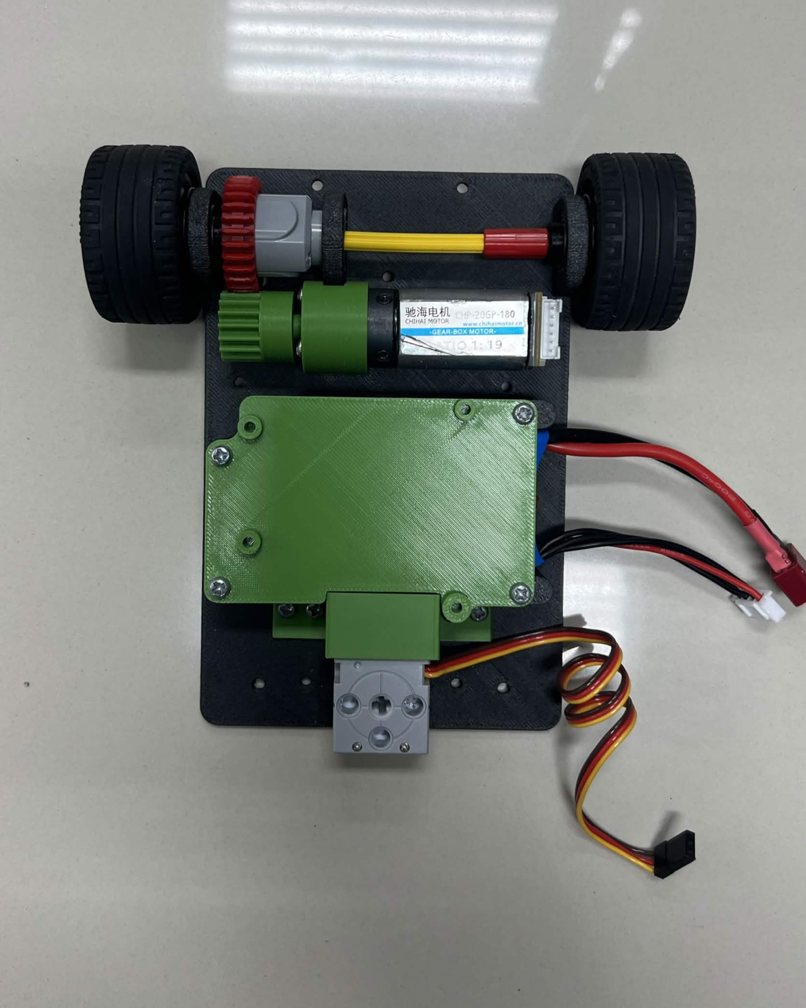
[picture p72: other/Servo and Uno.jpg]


The steering linkage should not be permanently installed until the servo center has been verified during actuator setup. This makes mechanical steering centering easier.

---

## 6.4 Assemble the Front Steering System

Install:

1. Steering Axle
2. Lower Steering Mount
3. Left Steering Arm
4. Right Steering Arm
5. Steering Linkage
6. Top Steering Mount / Cap
7. Front wheels

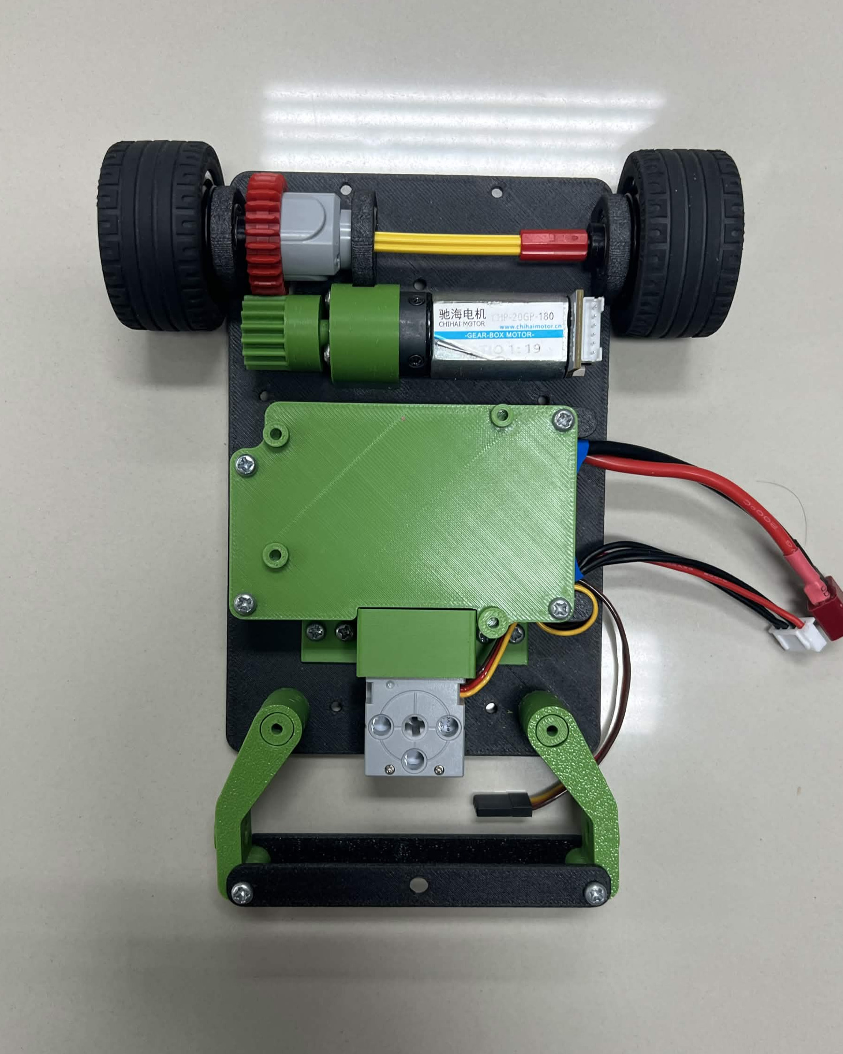
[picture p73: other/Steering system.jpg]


Relevant CAD files are documented in:

[`mech/mech_README.md`](mech/mech_README.md)

After assembly:

- move the steering manually,
- verify both wheels rotate freely,
- check for mechanical binding,
- verify the linkage does not contact the chassis.

---

## 6.5 Install Arduino and Motor Shield

Mount:

- Arduino UNO R4 Minima
- L298P Motor Shield
- XL4015 tray / converter assembly

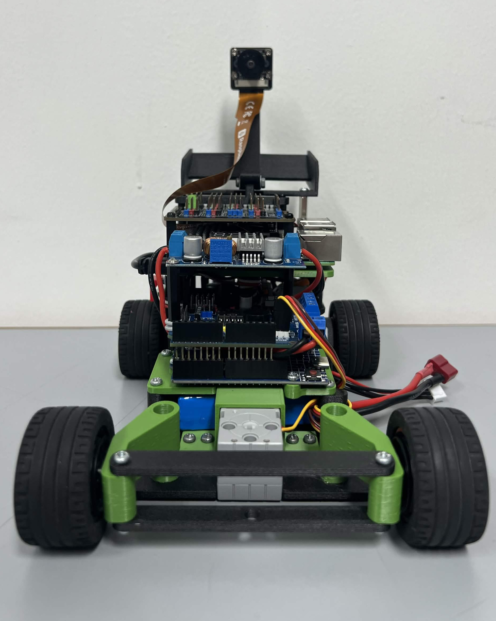
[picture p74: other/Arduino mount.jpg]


Keep enough space around the wiring terminals for later electrical inspection.

---

## 6.6 Install Raspberry Pi and DFR0566

Install the Raspberry Pi 5 onto its mounting plate. Then, mount the DFR0566 I/O Expansion HAT directly onto the Raspberry Pi header according to the board orientation.

Before installing upper structures:

- confirm no pin is misaligned,
- confirm no metal part can short the Raspberry Pi,
- verify the microSD card remains accessible.

---

## 6.7 Install Camera

Mount:

- camera plate,
- camera arm,
- camera connector / support,
- Raspberry Pi camera.

Connect the CSI cable without sharply folding it. Keep the camera mount adjustable, and do not permanently fix the final viewing angle until camera testing has been completed.

---

## 6.8 Install LiDAR and IMU

Mount the BNO055 underneath the LiDAR according to the final sensor layout. Then install the RPLiDAR C1 above the BNO055, ensuring that both sensors are securely positioned.

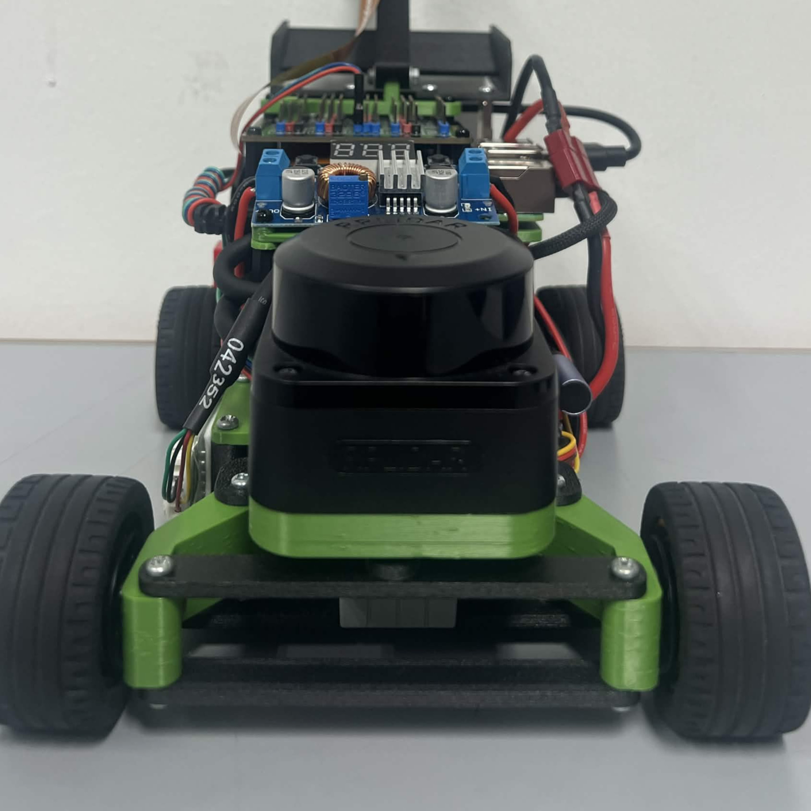
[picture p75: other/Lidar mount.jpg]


Important checks:

- LiDAR should be approximately parallel with the field,
- LiDAR rotation must not be physically obstructed,
- IMU should not move relative to the chassis,
- cables must not enter the LiDAR scanning area.

Sensor-placement reasoning is documented in:

[`elec/elec_README.md`](elec/elec_README.md)

---

## 6.9 Mechanical Inspection

Before beginning electrical assembly:

- [ ] all wheels rotate freely
- [ ] differential rotates freely
- [ ] drive gears mesh correctly
- [ ] motor is rigidly mounted
- [ ] steering does not bind
- [ ] front wheels can turn left and right
- [ ] bearings remain seated
- [ ] camera assembly is secure
- [ ] LiDAR structure is rigid
- [ ] electronics plates are secure
- [ ] no screw contacts an exposed circuit board
- [ ] no loose printed component remains

---

# 7. Electrical Assembly and Wiring

Use both:

- [`schemes/Schematic Diagram.png`](schemes/Schematic%20Diagram.png)
- [`schemes/Wiring Diagram.png`](schemes/Wiring%20Diagram.png)

The schematic explains the **electrical relationship**.

The wiring diagram explains the **physical connections**.

Do not reproduce the electrical system only from photographs.

---

## 7.1 Main Power Distribution

Current final architecture:

```text
3S LiPo Battery
       |
       v
Main SPST Switch
       |
       v
D1-2 Positive Distribution
       |
       +--------------------+
       |                    |
       v                    v
    LM2596                XL4015
       |                    |
       v                    v
Raspberry Pi Branch    Motor / Control Branch
```

Negative / ground distribution uses:

```text
PCT-21
```

---

## 7.2 Wire the Main Switch

Connect:

```text
Battery Positive
       |
       v
SPST Main Switch
       |
       v
D1-2 Positive Distribution
```

The main switch must remove power from the robot's electrical system.

---

## 7.3 Connect the LM2596 Branch

Connect the LM2596 input to the positive power distribution and common ground. Use its output to supply the Raspberry Pi power branch.

Target:

```text
Approximately 5.1 V
```

**Do not connect the Raspberry Pi yet.** Voltage is verified in Section 8.

---

## 7.4 Connect the XL4015 Branch

Connect the XL4015 input to the positive power distribution and common ground. Its output supplies the motor and control-side power system.

Do not assume the previous draft value is correct without measuring the physical final robot.

---

## 7.5 Ground Distribution

Connect the required negative / ground paths to the PCT-21 distribution. Maintain a common electrical reference for signals shared between subsystems. Before powering the system, use a multimeter to check the ground connections for continuity.

---

## 7.6 Connect Raspberry Pi 5

After the LM2596 output has been verified:

1. power off the robot,
2. connect the regulated Raspberry Pi supply,
3. confirm polarity,
4. inspect the USB-C power wiring,
5. confirm there is no exposed conductor.

---

## 7.7 Connect BNO055 IMU

The BNO055 communicates through I²C.

Connect:

```text
BNO055
   |
   v
DFR0566 I²C interface
   |
   v
Raspberry Pi
```

Use the I²C / Gravity connector corresponding to the final wiring diagram.

---

## 7.8 Connect Raspberry Pi Camera

Connect the camera through the Raspberry Pi CSI interface.

Check:

- CSI connector orientation,
- ribbon-cable direction,
- locking tab.

Do not insert or remove the CSI cable while the Raspberry Pi is powered.

---

## 7.9 Install Motor Shield

Mount the L298P Motor Shield onto the Arduino UNO R4 Minima according to the final hardware configuration. Then connect the motor and control wiring as shown in the wiring diagram.

---

## 7.10 Connect Drive Motor and Encoder

Current documented encoder wiring:

 

Arduino pins:

```text
Encoder A      -> D2
Encoder B      -> D3
Motor PWM      -> D11
Motor Direction-> D13
```

---

## 7.11 Connect Steering Servo

Current final servo control pin:

```text
Arduino D9
```

Servo connections:

```text
Signal
Positive
Ground
```

Check the electrical wiring diagram for the exact power path. Do not force the steering linkage against a mechanical end stop during initial testing.

---

## 7.12 Connect Start Button

The ZX-Switch01 is connected to:

```text
Arduino A0
```

Its purpose is not to power the robot.

The distinction is:

```text
SPST Main Switch
= Power On / Off

ZX-Switch01
= Start Autonomous Run
```

---

## 7.13 Connect Raspberry Pi ↔ Arduino

Connect the Arduino to the Raspberry Pi using a USB data cable.

Default device:

```text
/dev/ttyACM0
```

Serial configuration:

```text
115200 baud
```

The final robot currently routes this cable to one of the Raspberry Pi USB 3 ports. The exact physical USB port is less important than reliable device detection unless the final software explicitly assumes otherwise.

---

## 7.14 Connect RPLiDAR C1

Connect the RPLiDAR C1 through its adapter to the Raspberry Pi USB interface.

Default device:

```text
/dev/ttyUSB0
```

Current communication rate:

```text
460800 baud
```

The LiDAR cable must not interfere mechanically with the rotating sensor.

---

## 7.15 Cable Management

After all wiring is complete:

- secure loose wires,
- prevent cables from touching wheels,
- prevent cables from touching drivetrain gears,
- keep wires away from steering movement,
- prevent wires from entering the LiDAR scan / rotating area,
- provide strain relief near connectors.

Do not permanently secure all cables until the electrical verification tests pass.

---

# 8. Electrical Pre-Power Verification

This is one of the most important stages of reproduction.

Do **not** connect the Raspberry Pi or other sensitive loads until converter voltages are verified.

---

## 8.1 Power Verification Sequence

```text
Complete Power Wiring
       |
       v
Disconnect Sensitive Electronics
       |
       v
Inspect Polarity
       |
       v
Connect Battery
       |
       v
Turn Main Switch ON
       |
       v
Measure LM2596
       |
       v
Confirm ~5.1 V
       |
       v
Measure XL4015
       |
       v
Confirm Final Documented Voltage
       |
       v
Turn Power OFF
       |
       v
Connect Electronics
```

---

## 8.2 Multimeter Checklist

Before connecting electronics:

- [ ] battery polarity correct,
- [ ] no short between positive and ground,
- [ ] LM2596 input correct,
- [ ] LM2596 output approximately 5.1 V,
- [ ] XL4015 input correct,
- [ ] XL4015 output = 11.1,
- [ ] common ground continuity verified,
- [ ] no exposed conductor contacting chassis / PCB,
- [ ] connectors mechanically secure.

---

## 8.3 First Powered Electrical Test

After converter verification:

1. power off,
2. connect Raspberry Pi / control electronics,
3. lift drive wheels off the ground,
4. power on,
5. observe for unexpected heat, smell, sound or resets,
6. power off immediately if abnormal behavior occurs.

During this first test, do not run full-speed autonomous software.

---

# 9. Raspberry Pi Software Setup

The final software targets:

```text
Raspberry Pi 5
Raspberry Pi OS 64-bit
Python 3.11+
```

Python packages are managed with:

```text
uv
```

---

## 9.1 Prepare Raspberry Pi OS

Using Raspberry Pi Imager:

1. install Raspberry Pi OS 64-bit,
2. configure username / password,
3. configure network access if required,
4. enable SSH,
5. boot the Raspberry Pi.

---

## 9.2 Clone the Repository

Open a terminal on the Raspberry Pi:

```bash
cd ~
git clone https://github.com/chankrrn/WRO-FE-YBR-SUNFLOWER.git
cd WRO-FE-YBR-SUNFLOWER/src/Raspberrypi
```

For exact competition reproduction, the final tagged release should eventually be used instead of following the changing `main` branch.

See Section 17.

---

## 9.3 Run Setup Script

The repository contains:

```text
setup_pi.sh
```

Run:

```bash
bash setup_pi.sh
```

The setup script is intended to configure the required Linux packages, interfaces, permissions, `uv`, and Python environment.

When completed:

```bash
sudo reboot
```

The reboot is important because changes to group permissions, I²C configuration, and other system settings may not take effect until the system is restarted or the user logs in again.

---

## 9.4 Verify Raspberry Pi Interfaces

After reboot:

```bash
cd ~/WRO-FE-YBR-SUNFLOWER/src/Raspberrypi
```

Check I²C:

```bash
i2cdetect -y 1
```

Check USB serial devices:

```bash
ls /dev/ttyACM* /dev/ttyUSB*
```

Typical final configuration:

```text
Arduino -> /dev/ttyACM0
LiDAR   -> /dev/ttyUSB0
```

Actual numbering may change if USB devices are connected differently.

---

## 9.5 Install Python Environment

If `setup_pi.sh` already completed this successfully, no additional dependency installation should normally be necessary.

To verify:

```bash
uv sync
```

The environment is defined by:

```text
pyproject.toml
uv.lock
```

The lock file is important because it records reproducible Python dependency versions.

---

## 9.6 Dry Run

Before accessing the physical actuators:

```bash
uv run python main.py qualification --dry-run
```

Expected behavior:

- configuration loads,
- task plan is created,
- software exits without attempting normal hardware-driving behavior.

---

# 10. Arduino Setup and Firmware Upload

The final Arduino controller is:

```text
Arduino UNO R4 Minima
```

Firmware:

[`src/Arduino/Main.ino`](src/Arduino/Main.ino)

---

## 10.1 Arduino IDE

Install:

- Arduino IDE
- Arduino UNO R4 board package

Select:

```text
Board:
Arduino UNO R4 Minima
```

---

## 10.2 Required Libraries

Current firmware uses:

```text
Servo
PID_v2
```

The repository also contains library files associated with the Arduino firmware.

Existing Arduino Library Manager screenshots may remain as supporting instructions:

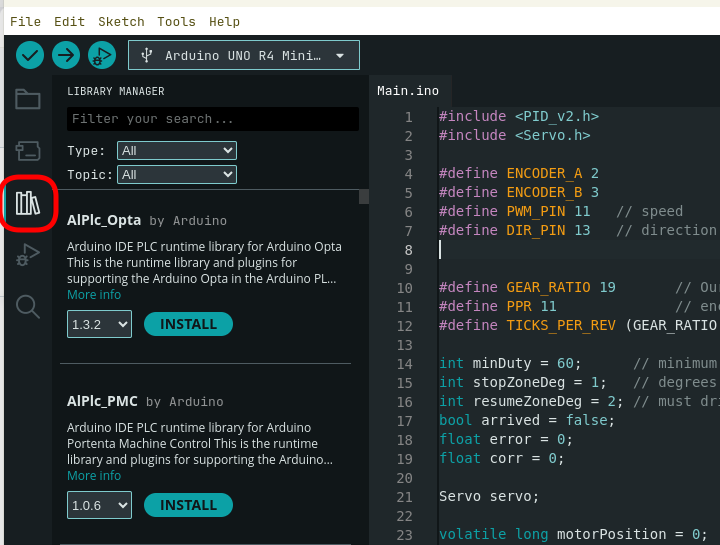
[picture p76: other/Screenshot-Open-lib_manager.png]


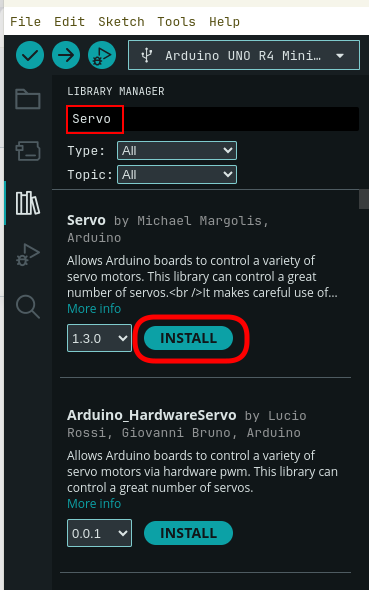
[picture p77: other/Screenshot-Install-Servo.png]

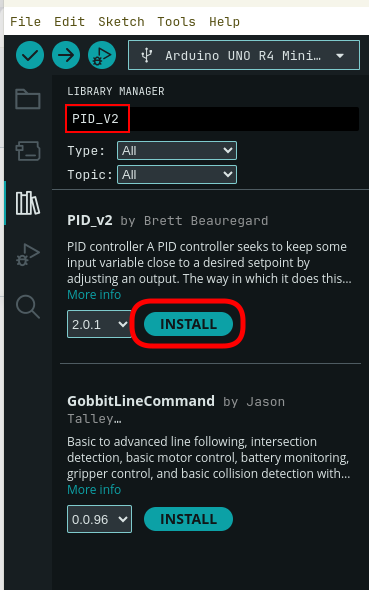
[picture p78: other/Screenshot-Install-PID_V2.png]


---

## 10.3 Upload Firmware

1. Open:

```text
src/Arduino/Main.ino
```

2. Select:

```text
Arduino UNO R4 Minima
```

3. Select the correct serial port.

4. Click **Upload**.

5. Wait for successful compilation and upload.

---

## 10.4 Verify Arduino Startup

Open Serial Monitor at:

```text
115200 baud
```

After initialization, the Arduino should return:

```text
READY
```

This confirms that the firmware has reached its initialized state.

---

## 10.5 Verify Start Button

With the robot waiting:

1. press the ZX-Switch01,
2. observe Arduino serial output.

Expected response:

```text
Start
```

---

# 11. Final Software Configuration

Competition parameters are stored primarily in:

```text
src/Raspberrypi/tasks/qualification/config.toml
```

and:

```text
src/Raspberrypi/tasks/final/config.toml
```

These configuration files contain adjustable values for the robot, including speed settings, clearance distances, Pure Pursuit lookahead, obstacle behavior, and path-planning parameters.

---

## 11.1 Do Not Re-Tune During Reproduction Unless Necessary

For exact reproduction:

1. use the final tagged repository version,
2. use its included configuration files,
3. first reproduce the robot behavior,
4. only then change tuning values if the reproduced mechanical platform differs.

---

# 12. Subsystem Verification

Do not immediately run the full autonomous challenge. Instead, test the system step by step.

---

## 12.1 Stage 1 — Electrical Verification

- [ ] main switch works
- [ ] Raspberry Pi supply measured correctly
- [ ] motor/control supply measured correctly
- [ ] common ground verified
- [ ] Raspberry Pi boots normally
- [ ] no unexpected component heating
- [ ] no undervoltage / reset behavior during idle operation

---

## 12.2 Stage 2 — Controller Communication

Verify:

```bash
ls /dev/ttyACM*
```

Arduino should be detected. Run the appropriate motor / serial test if available.

Expected Arduino initialization response:

```text
READY
```

---

## 12.3 Stage 3 — Steering Test

With drive wheels off the ground:

- [ ] servo centers
- [ ] left command moves left
- [ ] right command moves right
- [ ] linkage does not bind
- [ ] wheels do not exceed mechanical steering limits

After centering, connect / adjust the steering linkage mechanically if required.

---

## 12.4 Stage 4 — Drive Motor Test

With wheels lifted:

- [ ] positive command rotates wheels in forward direction
- [ ] negative command rotates wheels in reverse direction
- [ ] zero command stops motor
- [ ] gears do not skip
- [ ] drivetrain does not bind

---

## 12.5 Stage 5 — Encoder Test

Rotate / drive the drivetrain slowly.

Verify:

- [ ] Encoder A responds
- [ ] Encoder B responds
- [ ] count changes in expected direction
- [ ] reversing changes direction correctly
- [ ] count is repeatable over several rotations

---

## 12.6 Stage 6 — IMU Test

Run the IMU/software initialization, then rotate the robot by hand.

Verify:

- [ ] heading updates
- [ ] heading changes continuously
- [ ] sensor initializes through I²C
- [ ] no intermittent connection

---

## 12.7 Stage 7 — LiDAR Test

Verify that the LiDAR:

- [ ] rotates normally
- [ ] is detected by Linux
- [ ] returns scan data
- [ ] sees nearby walls / objects
- [ ] has no cable obstruction

The debug view can be used to verify whether the scan matches the surrounding geometry.

---

# 12.8 Stage 8 — Camera Test

Verify:

- [ ] camera stream opens
- [ ] image orientation is correct
- [ ] red pillar is detected as red
- [ ] green pillar is detected as green
- [ ] camera does not move mechanically during driving

Use:

```text
test_color_picker.py
```

if color thresholds require validation.

---

## 12.9 Stage 9 — Start Button

Verify:

- [ ] robot can remain powered while waiting
- [ ] pressing start button produces the start event
- [ ] autonomous timer begins after start
- [ ] main power switch and start switch remain independent

---

# 13. First Autonomous Run

The first autonomous test should be performed at reduced risk.

---

## 13.1 Pre-Run Inspection

Before placing the robot on the track:

- [ ] battery adequately charged
- [ ] no loose connectors
- [ ] LiDAR unobstructed
- [ ] camera secure
- [ ] wheels secure
- [ ] steering centered
- [ ] Pi / Arduino detected
- [ ] correct configuration selected
- [ ] debug mode available if required

---

## 13.2 Localization Test

Before completing full laps:

```bash
uv run python test_navigation.py
```

Verify that localization particles converge toward a reasonable robot pose. Do not proceed to high-speed testing if localization does not converge reliably.

---

## 13.3 Low-Speed Driving Test

Perform:

1. short straight drive
2. left turn
3. right turn
4. stop
5. repeat

Confirm:

- steering direction
- motor direction
- vehicle clearance
- drivetrain stability

---

## 13.4 Qualification / Open Challenge

Run:

```bash
uv run python main.py qualification
```

The robot should:

1. initialize,
2. wait for physical start,
3. capture its heading reference,
4. localize,
5. follow the racing line,
6. complete the task according to qualification logic,
7. stop safely.

---

## 13.5 Obstacle Challenge

Run:

```bash
uv run python main.py final
```

Debug mode:

```bash
uv run python main.py final --debug
```

The final task adds:

- traffic-pillar detection,
- obstacle map,
- racing-line deformation,
- obstacle passing,
- parking behavior.

---

# 14. Testing Workflow

Testing is an important part of the reproducible engineering workflow. The repository contains dedicated tools instead of requiring every change to be tested through a full competition run.

---

## 14.1 Recommended Development Workflow

```text
Change Code / Config
        |
        v
Dry Run
        |
        v
Simulation
        |
        v
Specific Subsystem Test
        |
        v
Low-Speed Physical Test
        |
        v
Full Track Test
        |
        v
Record Result
        |
        v
Commit Change
```

---

# 14.2 Software Test Tools

### Localization

```bash
uv run python test_navigation.py
```

### Repeated Driving Simulation

```bash
uv run python test_driving.py --trials 24
```

### Steering Parameter Sweep

```bash
uv run python test_steering.py --sweep speed.corner 40,50,60,70
```

### Color Calibration

```bash
uv run python test_color_picker.py
```

---

# 14.3 Testing Evidence

Testing evidence should be stored separately from source code.

Recommended structure:

```text
engineering-process/
└── testing/
    ├── mechanical/
    ├── electrical/
    ├── sensors/
    ├── software/
    └── competition/
```

For important tests, record:

```text
Date
Configuration / Commit
Test
Result
Failure
Change Made
```

---

# 14.4 Test Record Template

```markdown
## Test: [Name]

Date:
Commit:
Robot Version:

### Objective
[What are we trying to verify?]

### Configuration
[Important parameters]

### Method
[What was tested?]

### Result
[What happened?]

### Failure / Observation
[If applicable]

### Engineering Decision
[What changed because of this result?]
```

---

# 15. Troubleshooting

Follow the troubleshooting steps in order. Avoid changing multiple configuration values at the same time, as this makes it more difficult to identify the cause of a problem.

---

## 15.1 Raspberry Pi Does Not Detect Arduino

### Symptom

```text
/dev/ttyACM0
```

does not appear.

### Check

```bash
ls /dev/ttyACM*
```

Then check:

- USB cable supports data,
- Arduino is powered,
- correct USB port,
- firmware uploaded.

Try pressing the Arduino reset button once.

If the device appears but access is denied:

```bash
groups
```

Confirm that the user has the required serial-device permissions. The repository setup script is intended to configure these permissions.

---

## 15.2 Raspberry Pi Does Not Detect LiDAR

### Check

```bash
ls /dev/ttyUSB*
```

Then inspect:

- LiDAR power
- USB adapter
- USB cable
- connector seating

If the device exists but permission is denied, inspect:

```bash
ls -l /dev/ttyUSB0
groups
```

Use the permanent user / device-permission setup rather than relying on temporary world-writable permissions.

---

## 15.3 BNO055 Not Detected

Run:

```bash
i2cdetect -y 1
```

Check:

- I²C enabled
- DFR0566 seated correctly
- I²C cable
- SDA / SCL connection
- power and ground

---

## 15.4 Camera Not Available

Check:

- CSI ribbon orientation
- CSI locking connector
- camera cable damage
- camera configuration
- Raspberry Pi reboot after setup

Then test camera functionality before running competition software.

---

## 15.5 Servo Jitters or Resets

Possible causes:

- unstable servo supply,
- voltage drop,
- mechanical binding,
- poor ground connection,
- excessive load.

Check:

1. supply voltage
2. common ground
3. steering mechanism by hand
4. servo behavior with drivetrain stopped

---

## 15.6 Raspberry Pi Resets During Acceleration

Possible cause: actuator-related power disturbance or Pi supply voltage drop.

Check:

1. Raspberry Pi branch voltage while motor starts
2. LM2596 output under load
3. connectors
4. common ground
5. battery state

---

## 15.7 Motor Rotates in Wrong Direction

Do not change several software signs simultaneously.

First verify:

- motor wiring polarity
- Arduino direction convention
- software forward command

Document the final convention after correcting it.

---

## 15.8 Encoder Counts in Wrong Direction

Check:

- Encoder A / B wiring
- D2 / D3 assignment
- motor rotation direction

Swapping encoder A and B changes quadrature direction.

---

## 15.9 LiDAR Map Looks Distorted

Check the physical mounting first. The LiDAR scan plane should be approximately parallel to the field surface. A tilted LiDAR can produce incorrect 2D geometry even when communication is working correctly.

---

## 15.10 Robot Localizes Incorrectly

Check:

1. LiDAR data
2. LiDAR physical orientation
3. IMU heading
4. field-map configuration
5. start pose / configuration
6. particle convergence

Use:

```bash
uv run python test_navigation.py
```

and debug visualization before changing path-following parameters.

---

## 15.11 Camera Detects Wrong Pillar Color

Use:

```bash
uv run python test_color_picker.py
```

Check:

- lighting
- exposure
- final camera FOV
- HSV thresholds

Do not increase threshold ranges without checking real camera values.

---

# 16. Competition Startup Procedure

Once the robot has passed the reproduction tests, use the following competition startup sequence.

```text
Inspect Robot
      |
      v
Check Battery
      |
      v
Place Robot
      |
      v
Main Power ON
      |
      v
Wait for Pi + Arduino Initialization
      |
      v
Confirm Sensors
      |
      v
Start Correct Competition Task
      |
      v
Robot Waits for ZX-Switch01
      |
      v
Press Start Button
      |
      v
Initial Heading Captured
      |
      v
Autonomous Run Begins
```

---

## 16.1 Open Challenge

```bash
cd ~/WRO-FE-YBR-SUNFLOWER/src/Raspberrypi
uv run python main.py qualification
```

---

## 16.2 Obstacle Challenge

```bash
cd ~/WRO-FE-YBR-SUNFLOWER/src/Raspberrypi
uv run python main.py final
```

---

# 17. Version Lock and Competition Release

A reproducible robot requires more than the latest `main` branch. The exact competition version should be permanently identifiable.

---

## 17.1 Reproduce the Exact Competition Version

After cloning:

```bash
cd ~/WRO-FE-YBR-SUNFLOWER
```

Verify:

```bash
git rev-parse HEAD
```

The returned commit should match the final documented competition SHA.

---

# 18. Reproducibility Checklist

## 18.1 Documentation

- [ ] Main README available
- [ ] Mechanical README available
- [ ] Electrical README available
- [ ] Software README available
- [ ] BUILD guide available
- [ ] Schematic available
- [ ] Wiring diagram available
- [ ] CAD / STL files available
- [ ] Source code available
- [ ] Final release / tag documented
- [ ] CHANGELOG available

---

## 18.2 Mechanical

- [ ] all required printed parts identified
- [ ] final V3 parts separated from prototypes
- [ ] drivetrain assembled
- [ ] differential works
- [ ] bearings installed
- [ ] steering works freely
- [ ] servo installed
- [ ] wheels installed
- [ ] electronics layers installed
- [ ] camera mounted
- [ ] LiDAR / IMU mounted

---

## 18.3 Electrical

- [ ] battery polarity documented
- [ ] LM2596 output documented
- [ ] XL4015 output documented
- [ ] common ground verified
- [ ] Raspberry Pi powered correctly
- [ ] Arduino powered correctly
- [ ] motor wired
- [ ] servo wired
- [ ] encoder wired
- [ ] IMU connected
- [ ] camera connected
- [ ] LiDAR connected
- [ ] start button connected
- [ ] wiring matches schematic

---

## 18.4 Software

- [ ] Raspberry Pi OS version documented
- [ ] repository cloned
- [ ] final release checked out
- [ ] `setup_pi.sh` completed
- [ ] `uv sync` succeeds
- [ ] Arduino firmware uploaded
- [ ] Arduino libraries / versions documented
- [ ] dry run succeeds

---

## 18.5 Subsystem Tests

- [ ] Arduino detected
- [ ] LiDAR detected
- [ ] IMU detected
- [ ] camera works
- [ ] motor direction correct
- [ ] steering direction correct
- [ ] steering center correct
- [ ] encoder works
- [ ] start switch works
- [ ] localization converges
- [ ] low-speed drive succeeds

---

## 18.6 Competition Functions

- [ ] Open Challenge task starts correctly
- [ ] robot follows racing line
- [ ] red pillar detected
- [ ] green pillar detected
- [ ] red pillar passed on correct side
- [ ] green pillar passed on correct side
- [ ] parking sequence operates
- [ ] timeout stops run
- [ ] software exception cleanup stops drivetrain

---

# 19. Related Documentation

For design reasoning, use:

### Mechanical

[`mech/mech_README.md`](mech/mech_README.md)

### Electrical and Sensors

[`elec/elec_README.md`](elec/elec_README.md)

### Software

[`software/software_README.md`](software/software_README.md)

### Electrical Schematic

[`schemes/Schematic Diagram.png`](schemes/Schematic%20Diagram.png)

### Physical Wiring Diagram

[`schemes/Wiring Diagram.png`](schemes/Wiring%20Diagram.png)

### Source Code

[`src/`](src/)

---

# Final Reproduction Principle

A robot is not reproducible simply because its source code and CAD files are public.

Reproduction requires enough information to answer:

```text
What parts are required?
How are they manufactured?
How are they assembled?
How are they wired?
What voltage should each rail have?
What software version should be installed?
How is the firmware uploaded?
How is each subsystem verified?
What tests must pass before autonomous driving?
Which exact repository version produced the competition robot?
```

The objective of this guide is therefore:

> **Another builder should not need to reverse-engineer YBR-SUNFLOWER from photographs or guess undocumented settings.**

The final reproduction process is:

> **Manufacture → Assemble → Wire → Measure → Configure → Verify → Test → Run**

and should lead to the same Version 3 hardware and competition software documented throughout this repository.

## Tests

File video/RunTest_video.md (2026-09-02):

## Run Test
### Challenge 1 (Open Challenge):
test 1 - No test video for Open Challenge

### Challenge 2 (Obstacle Challenge):
test 1 - https://youtu.be/UcIF2pgKeVI?si=_V3N1U0dxUIEpj_h

test 2 - https://youtu.be/SdUwbpnx7VY?si=cszDUZWCZ1XHu-8N

test 3 (Debugging Interface) - https://youtu.be/8UqM-YWCEpo

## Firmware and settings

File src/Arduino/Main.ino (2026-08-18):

#include <PID_v2.h>
#include <Servo.h>

#define ENCODER_A 2
#define ENCODER_B 3
#define PWM_PIN 11   // speed
#define DIR_PIN 13   // direction


#define GEAR_RATIO 19       // Our CHP-20GP-180's gear ratio
#define PPR 11              // encoder pulses per motor-shaft revolution
#define TICKS_PER_REV (GEAR_RATIO * PPR * 4.0) // x4 quadrature decoding

int minDuty = 60;      // minimum PWM to overcome friction
int stopZoneDeg = 1;   // degrees considered "arrived"
int resumeZoneDeg = 2; // must drift this far from target before correcting again
bool arrived = false;
float error = 0;
float corr = 0;

Servo servo;

volatile long motorPosition = 0;
volatile uint8_t lastEncoded = 0;

double currentDeg, targetDeg, output;
double kp = 0.33, ki = 0.0, kd = 0.007;
PID myPID(&currentDeg, &output, &targetDeg, kp, ki, kd, DIRECT);

// ---------- Serial command buffer ----------
String serialBuf = "";

void updateMotorPosition() {
  uint8_t MSB = digitalRead(ENCODER_A);
  uint8_t LSB = digitalRead(ENCODER_B);
  uint8_t encoded = (MSB << 1) | LSB;
  uint8_t sum = (lastEncoded << 2) | encoded;

  if (sum == 0b1101 || sum == 0b0100 || sum == 0b0010 || sum == 0b1011) motorPosition++;
  if (sum == 0b1110 || sum == 0b0111 || sum == 0b0001 || sum == 0b1000) motorPosition--;

  lastEncoded = encoded;
}

void setup() {
  Serial.begin(115200);
  servo.attach(9);
  pinMode(ENCODER_A, INPUT_PULLUP);
  pinMode(ENCODER_B, INPUT_PULLUP);
  attachInterrupt(digitalPinToInterrupt(ENCODER_A), updateMotorPosition, CHANGE);
  attachInterrupt(digitalPinToInterrupt(ENCODER_B), updateMotorPosition, CHANGE);
  pinMode(PWM_PIN, OUTPUT);
  pinMode(DIR_PIN, OUTPUT);

  myPID.SetMode(AUTOMATIC);
  myPID.SetOutputLimits(-255, 255);
  myPID.SetSampleTime(10);

  servo.write(cal_head(0)); // center steering
  serialBuf.reserve(32);

  Serial.println("READY");
  StartButton();
}

void motor_degree(float angle) {
  targetDeg = angle; // set the GLOBAL setpoint the PID actually reads

  do {
    currentDeg = motorPosition * 360.0 / TICKS_PER_REV; // update the GLOBAL currentDeg
    error = abs(targetDeg - currentDeg);

    myPID.Compute();
    corr = constrain(abs((int)output), 0, 100);
    if (corr > 0 && corr < minDuty && error > 5) corr = minDuty;
    digitalWrite(DIR_PIN, output >= 0 ? HIGH : LOW);
    analogWrite(PWM_PIN, corr);
  } while (error > 2);

  analogWrite(PWM_PIN, 0);
}

void motor_dc(int duty) {
  digitalWrite(DIR_PIN, duty >= 0 ? HIGH : LOW);
  analogWrite(PWM_PIN, constrain(abs(duty), 0, 255));
}

// Calculate the seering angle to make it useable with our servo
int cal_head(int degree) {
  return ((degree + 180) / 2);
}

// ---------- Serial command handling ----------
// Protocol (newline-terminated ASCII lines), comma-separated tuple:
//   <servoAngle>,<speed>,<distance>
//     servoAngle : int, degrees, passed through cal_head() and applied immediately
//     speed      : int, raw PWM duty -255..255 (sign = direction)
//     distance   : float, degrees of motor travel
//                    0    -> just drive continuously at <speed>, replies "OK" right away (non-blocking)
//                    !=0  -> drive at <speed> until |distance| degrees have been traveled
//                            (measured from encoder position at command start), then stop
//                            and print "t"
// Malformed lines reply "ERR"
void handleCommand(String cmd) {
  cmd.trim();
  if (cmd.length() == 0) return;

  int c1 = cmd.indexOf(',');
  int c2 = (c1 >= 0) ? cmd.indexOf(',', c1 + 1) : -1;
  if (c1 < 0 || c2 < 0) {
    Serial.println("ERR");
    return;
  }

  int servoAngle = cmd.substring(0, c1).toInt();
  int speed = cmd.substring(c1 + 1, c2).toInt();
  float distance = cmd.substring(c2 + 1).toFloat();

  servo.write(cal_head(servoAngle));

  if (distance == 0) {
    motor_dc(speed);
    Serial.println("OK");
  } else {
    long startPos = motorPosition;
    motor_dc(speed);

    float traveled;
    do {
      traveled = abs((motorPosition - startPos) * 360.0 / TICKS_PER_REV);
    } while (traveled < abs(distance));

    analogWrite(PWM_PIN, 0);
    Serial.println("t");
  }
}

void readSerialCommands() {
  while (Serial.available() > 0) {
    char c = (char)Serial.read();
    if (c == '\n') {
      handleCommand(serialBuf);
      serialBuf = "";
    } else if (c != '\r') {
      serialBuf += c;
      // guard against runaway buffer if newline never arrives
      if (serialBuf.length() > 40) serialBuf = "";
    }
  }
}

void StartButton(){
  while (analogRead(0) > 500){
    delay(10);
  }
  delay(800);
  Serial.println("Start");

}

void loop() {
  readSerialCommands();
}

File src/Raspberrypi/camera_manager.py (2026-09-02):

try:
    from picamera2 import Picamera2
except ImportError as exc:
    # The stub only exists so hsv_adjuster can be run off-Pi. On the Pi this
    # branch means the interpreter cannot see the system picamera2 - almost
    # always a venv built without --system-site-packages - and every frame
    # would silently come back empty. Say so instead of failing later with an
    # unrelated AttributeError deep inside configure_camera().
    print(f"WARNING: picamera2 unavailable ({exc}); falling back to the "
          f"fake_picamera2 stub - NO real frames will be captured.")
    from utils.fake_picamera2 import Picamera2
import time
from utils.image_transform_utils import ImageTransformUtils
from utils.image_transform_utils import ImageColorUtils
import cv2
import numpy as np
from utils.enums import Color
from utils.image_drawing_utils import ImageDrawingUtils
import math
import os
from utils.video.video_counter import VideoCounter
from classes.image_algoriths import ImageAlgorithms
from classes.context_manager import ContextManager

class CameraManager:

    def __init__(self, record_video=False, record_fps=15.0):
        """
        I/O:
            record_video: write every frame the round sees to videos/videoN.mp4.
                          Off by default because it costs a full-frame copy per
                          frame - the display image the writer needs is
                          otherwise only taken when something is going to draw
                          on it.
            record_fps:   the rate frames will actually ARRIVE at, which is the
                          vision thread's, not the camera's.
        """
        self.record_video = bool(record_video)
        self.record_fps = float(record_fps)
        self.video_output = None
        self.previous_time = 0

        self.picam2 = Picamera2()
        self.raw_image = None
        self.cropped_image = None
        self.colormask_image = None
        
        self.blue_mask = None
        self.orange_mask = None
        self.green_mask = None
        self.red_mask = None
        self.pink_mask = None
        self.blueline_image = None
        self.orangeline_image = None
        self.clean_blueline_image = None
        self.clean_orangeline_image = None
        self.cnt_blueline = None    # to delete and change place
        self.cnt_orangeline = None  # to delete and change place
        self.length_blue = None      # to delete and change place
        self.length_orange = None    # to delete and change place
        self.grayscale_image = None
        self.blurred_image = None
        self.binary_image = None
        self.clean_image = None
        self.polygon_image = None
        self.polygon_lines = None
        self.combined_mask = None
        self.with_pink_combined_mask = None
        self.grayscale_image = None
        self.binary_obstacle = None
        self.obstacle_image = None
        self.pink_obstacle_image = None
        self.contour_obstacle = None
        self.pink_image = None
        
        self.hsv_image = None

        # the image used to display all the relevant info
        self.display_image = None

        self.configure_camera()

    def configure_camera(self):
        sensor_mode = self.picam2.sensor_modes[1]
        sensor_width, sensor_height = sensor_mode["size"]
        # A VIDEO configuration, not a still one. A still config allocates a
        # single buffer and runs the ISP in its highest-quality mode, so every
        # capture_array() waits out a whole frame with nothing queued behind
        # it - which is exactly the wrong trade for a stream of frames that
        # only ever gets thresholded into colour masks.
        #
        # The raw size stays pinned to sensor_modes[1]. That is what fixes the
        # sensor mode, and the sensor mode is what ObjectSolver's measured
        # CAPTURED_HORIZONTAL_FOV_DEG describes - let libcamera pick its own
        # and every distance the pillar solver reports is quietly wrong.
        config = (self.picam2.create_video_configuration(
        raw={"size":(sensor_width,sensor_height)},
        main={"format":'RGB888',"size": (ImageTransformUtils.CAMERA_PIC_WIDTH, ImageTransformUtils.CAMERA_PIC_HEIGHT)},
        buffer_count=4))
        self.picam2.configure(config)
        
        if self.record_video:
            self.configure_video_output()

    def configure_video_output(self):
        output_folder = os.path.join(os.path.dirname(__file__), "../videos")
        os.makedirs(output_folder, exist_ok=True)
        
        output_path = os.path.join(output_folder, f"video{VideoCounter.get_video_counter()}.mp4")
        
        fourcc = cv2.VideoWriter_fourcc(*'mp4v')
        # THE FPS HAS TO MATCH THE LOOP THAT FEEDS IT. Frames arrive at the
        # vision thread's rate, not at 25/s, and a writer told the wrong
        # number does not drop or duplicate anything - it just stamps the
        # frames with the wrong timebase, so the whole round plays back at the
        # wrong speed. 15 in, 25 declared, is a video that runs 1.7x fast.
        self.video_output = cv2.VideoWriter(
            output_path, fourcc, float(self.record_fps),
            (ImageTransformUtils.PIC_WIDTH, ImageTransformUtils.PIC_HEIGHT))
        if not self.video_output.isOpened():
            print(f"WARNING: could not open {output_path} for writing - the run "
                  f"will not be recorded")
            self.video_output = None
            return
        print(f"Recording to {output_path} at {self.record_fps:.0f}fps")
        VideoCounter.increment_video_counter()
        
    def start_camera(self):
        self.picam2.start()
        time.sleep(2)

    def capture_image(self):
        if self.raw_image is not None:
            del self.raw_image
        self.raw_image = self.picam2.capture_array()
        if self.previous_time != 0:
            pass
            #print(f"Delay between frames: {time.time() - self.previous_time:.3f} seconds")
        self.previous_time = time.time()
        
    def capture_for_blocks(self, with_display=False):
        """
        Everything ObjectSolver needs from a frame, and nothing else.

        transform_image() builds the whole vision pipeline: the grayscale /
        binary / polygon stack, the blue and orange line rectangles, the pink
        and obstacle masks. The obstacle round reads exactly two of its
        products - hsv_image, and display_image only when something is going
        to draw on it - so it spends most of a frame computing answers no
        caller ever asks for.

        Measured on a Pi 5 against a 640x280 mat frame, OpenCV single
        threaded:

            transform_image()          19.6 ms
            this                        0.8 ms

        That difference is not academic: at CAMERA_EVERY_N_TICKS the round was
        paying it on every other 20ms control tick.
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

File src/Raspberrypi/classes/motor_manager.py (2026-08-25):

import glob
import os
import time
from collections import deque

import serial

from utils.angle_utils import clamp

# ============================================================================
# Serial link to the Arduino
# ============================================================================
DEFAULT_PORT = "/dev/ttyACM0"
DEFAULT_BAUD = 115200
SERIAL_TIMEOUT_S = 0.1
# A write must never be able to park the control loop either. The line is
# 115200 baud and the messages are ~12 bytes, so anything approaching this
# means the link is not draining and no amount of waiting will fix it.
SERIAL_WRITE_TIMEOUT_S = 0.05

# The Arduino UNO R4 enumerates as /dev/ttyACM*; matching the USB descriptor
# keeps autodetect off the lidar's CP2102N bridge on /dev/ttyUSB0.
USB_ID_HINTS = ("Arduino", "UNO")

# The Arduino resets when the port is opened and prints a banner when ready.
ARDUINO_BOOT_S = 2.0

MAX_STEER_DEG = 50
STEER_SMOOTHING_WINDOW = 3

# drive() skips the serial round-trip when nothing has meaningfully changed.
# The control loop runs far faster than the robot can respond, so most ticks
# ask for the same thing as the last one; at 50Hz, re-sending it is the
# difference between a loop paced by the code and one paced by the UART.
STEER_DEADBAND_DEG = 1.0
SPEED_DEADBAND = 1

DRIVE_DISTANCE_TIMEOUT_S = 30.0
DONE_REPLY = "t"          # what the Arduino sends when a queued move finishes


class MotorManager:
    """
    Drive motor + steering, spoken to over serial as one command per line:

        "<angle>,<speed>,<distance>\\n"

    where angle is steering in degrees (- left / + right), speed is 0-100, and
    distance is degrees of motor-shaft rotation (0 = keep going until told
    otherwise). The Arduino answers every command with a line, and answers a
    non-zero distance move with "t" once the move has actually finished.

    Those replies are ACKNOWLEDGEMENTS, not data - nothing in the control loop
    reads one - so drive() does not wait for them. It writes and returns, and
    drains whatever has arrived since last time on the way past. Waiting cost
    the loop a serial round-trip per command in the good case and the port's
    full 0.1s timeout in the bad one, mid-corner, for a line nobody was going
    to look at. drive_distance() and wait_for_start() still read, because for
    those the reply IS the answer.

    With `drive_enabled=False` the speed field of every message is forced to
    zero on the way out (see _send), which is the one place all of them pass
    through - steering, stops and queued moves included.
    """

    def __init__(self, port=None, baudrate=DEFAULT_BAUD, debug=False, drive_enabled=True):
        self.port = port or self.autodetect_port()
        self.baudrate = baudrate
        self.debug = debug
        # False (--no-drive) means the steering servo still does everything it
        # normally would, but every command leaves the Pi with speed 0 - so
        # the round can be walked through by hand, pushing the robot along
        # while watching the wheels answer the real control loop.
        self.drive_enabled = drive_enabled

        self.serial = None
        self.current_speed = 0
        self.current_angle = 0
        self.steering_history = deque(maxlen=STEER_SMOOTHING_WINDOW)
        # Acknowledgements read and thrown away, and writes that timed out.
        # Neither is ever acted on - but a run that ends having drained zero
        # replies means the Arduino was not answering at all, and that is
        # worth being able to see afterwards.
        self.replies_dropped = 0
        self.write_failures = 0

    # ========================================================================
    # LIFECYCLE
    # ========================================================================

    @staticmethod
    def autodetect_port():
        for path in sorted(glob.glob("/dev/serial/by-id/*")):
            if any(hint in os.path.basename(path) for hint in USB_ID_HINTS):
                return os.path.realpath(path)
        return DEFAULT_PORT

    def start(self):
        self.serial = serial.Serial(self.port, self.baudrate, timeout=SERIAL_TIMEOUT_S,
                                    write_timeout=SERIAL_WRITE_TIMEOUT_S)
        time.sleep(ARDUINO_BOOT_S)   # the port opening resets the board
        banner = self.serial.readline().decode(errors="ignore").strip()
        if self.debug:
            print(f"[motor] {self.port} @ {self.baudrate}, arduino says: {banner!r}")
        if not self.drive_enabled:
            print("  DRIVE MOTOR DISABLED - steering only, push the robot by hand")
        self.current_speed = 0
        self.current_angle = 0
        self.steering_history.clear()
        self.replies_dropped = 0
        self.write_failures = 0

    def stop_and_close(self):
        try:
            self.stop()
            self.steer_center()
            time.sleep(0.1)
        except Exception:
            pass
        if self.serial is not None:
            try:
                self.serial.close()
            except Exception:
                pass
            self.serial = None

    @property
    def is_connected(self):
        return self.serial is not None and self.serial.is_open

    # ========================================================================
    # DRIVING
    # ========================================================================

    def _send(self, angle, speed, distance=0, wait_for_reply=True):
        if self.serial is None:
            raise RuntimeError("MotorManager.start() must be called first")
        if not self.drive_enabled:
            speed = 0
        try:
            self.serial.write(f"{int(angle)},{int(speed)},{int(distance)}\n".encode())
        except serial.SerialTimeoutException:
            # The link is not draining. Counted and carried on rather than
            # raised: losing one steering command is survivable, ending the
            # round in the middle of a corner is not.
            self.write_failures += 1
            if self.write_failures in (1, 10) or self.write_failures % 100 == 0:
                print(f"WARNING: motor serial write timed out "
                      f"({self.write_failures} so far) - is the Arduino alive?")
            return None
        if wait_for_reply:
            return self.serial.readline().decode(errors="ignore").strip()
        return None

    def drain_replies(self):
        """
        Throws away acknowledgements that have piled up, without blocking.

        Somebody has to read them. The Arduino answers every command, so a
        three-minute round leaves thousands of lines in the kernel's receive
        buffer if nothing ever does - and then the first caller that wants a
        REAL reply (drive_distance waiting for its "t") reads the backlog
        instead of the answer.
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

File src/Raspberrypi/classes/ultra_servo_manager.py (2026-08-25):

from utils.angle_utils import clamp

# ============================================================================
# Hardware wiring
# ============================================================================
SERVO_CHANNEL = 0          # expansion board PWM channel the servo sits on
ULTRA_ADC_CHANNEL = 0      # expansion board ADC channel the URM09 sits on

SERVO_CENTER_DEG = 45      # servo angle that points the sensor straight ahead
SERVO_LEFT_DEG = 90        # ... at the left-hand wall
SERVO_RIGHT_DEG = 0        # ... at the right-hand wall
SERVO_MIN_DEG = 0
SERVO_MAX_DEG = 50

# How hard the head counter-rotates against the robot's heading error, so it
# keeps pointing at the same patch of wall while the body yaws.
TRACKING_GAIN = 2.0
TRACKING_DEADBAND_DEG = 3

# URM09 analog: full scale is 500cm across the supply voltage.
URM09_MAX_RANGE_CM = 500.0
VIN_MV = 5000              # 3300 if the URM09 is powered from the 3.3V rail


class UltraServoManager:
    """
    The steerable ultrasonic head: a servo on the expansion board carrying a
    URM09 whose analog output comes back on an ADC channel of the same board.

    The head points at the wall the robot is following. As the body yaws off
    its target heading the head rotates the opposite way (update_tracking), so
    the beam stays on the wall instead of sweeping along it - a wall reading
    taken at an angle reads longer than the true perpendicular distance and
    would otherwise fight the wall-following controller.

    read_raw() is in ADC millivolts, which is the unit the wall-following
    constants are tuned in. read_distance_cm() converts to centimeters.
    """

    def __init__(self, board_manager, debug=False,
                 servo_channel=SERVO_CHANNEL, adc_channel=ULTRA_ADC_CHANNEL):
        self.board_manager = board_manager
        self.debug = debug
        self.servo_channel = servo_channel
        self.adc_channel = adc_channel

        self.servo = None
        self.angle = SERVO_CENTER_DEG
        self.base_angle = SERVO_CENTER_DEG   # where the head sits at zero yaw error

    # ========================================================================
    # LIFECYCLE
    # ========================================================================

    def start(self):
        self.servo = self.board_manager.create_servo()
        self.center()
        if self.debug:
            print(f"[ultra] servo on channel {self.servo_channel}, "
                  f"URM09 on ADC {self.adc_channel}")

    def stop(self):
        try:
            self.center()
        except Exception:
            pass
        self.servo = None

    # ========================================================================
    # POINTING
    # ========================================================================

    def move(self, angle):
        if self.servo is None:
            raise RuntimeError("UltraServoManager.start() must be called first")
        self.angle = clamp(angle, SERVO_MIN_DEG, SERVO_MAX_DEG)
        self.servo.move(self.servo_channel, int(self.angle))

    def center(self):
        self.base_angle = SERVO_CENTER_DEG
        self.move(SERVO_CENTER_DEG)

    def point_at_wall(self, turn_direction):
        """
        Aims the head at the wall the robot follows for this lap direction.
        "L" (counter-clockwise laps) follows the left wall, "R" the right.
        """
        self.base_angle = SERVO_LEFT_DEG if turn_direction == "L" else SERVO_RIGHT_DEG
        self.move(self.base_angle)

    def update_tracking(self, heading_offset, deadband_deg=TRACKING_DEADBAND_DEG):
        """
        Counter-rotates the head by the robot's heading error so the beam
        stays on the same patch of wall. Small errors inside the deadband are
        ignored, otherwise the head would buzz constantly on sensor noise.
        """
        if self.servo is None:
            return
        offset = heading_offset if abs(heading_offset) > deadband_deg else 0
        self.move(self.base_angle - offset * TRACKING_GAIN)

    # ========================================================================
    # RANGING
    # ========================================================================

    def read_raw(self):
        """Raw ADC millivolts from the URM09, or None if the read failed."""
        return self.board_manager.read_adc(self.adc_channel)

    def read_distance_cm(self):
        """Distance in centimeters, or None if the read failed."""
        raw = self.read_raw()
        if raw is None:
            return None
        return raw * URM09_MAX_RANGE_CM / VIN_MV

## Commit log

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2026-08-18 new file: .gitignore new file: pyproject.toml new file: src/camera_manager.py new file: src/classes/block_map.py new file: src/classes/board_manager.py new file: src/classes/compass_manager.py new fi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
2026-08-20 Add 3D models STL file
    [ElecBase.stl, MainBase.stl, PiBase.stl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]
2026-08-20 Added 3D models STL file via Upload
    [CamArm.stl, CamArmConnector.stl, CamMount.stl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]
2026-08-20 Updated mech_README.md
    Updated the mech README to include detailed descriptions and links for various components, including the Main Base, Supporting Bases, and additional parts like the Servo Bracket and Camera Mount.
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2026-08-21 Revise mech_README.md
    Updated the mech README to enhance clarity and detail regarding the mechanical design approach, structural prototypes, and various components of the robot. Added images, improved descriptions, and or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
2026-08-22 Skip the unused half of the camera pipeline in the obstacle round
    transform_image() builds the whole vision stack - grayscale/binary/polygon,
    the blue and orange line rectangles, the pink and obstacle masks - and the
    obstacle round reads two of its products: hsv_image, plus display_image only
    when the solver is drawing an overlay.
    Measured on a Pi 5 against a 640x280 mat frame, OpenCV single threaded:
    crop + bgr_to_hsv 0.77 ms needed
    remove_color(ALL) + gray/blur/binary 13.44 ms unused
    5x calculate_color_mask 1.38 ms unused
    draw_polygon 0.13 ms unused
    line + obstacle find_rect 3.90 ms unused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
    [camera_manager.py]
2026-08-22 Make the block map safe to feed from a thread that is not the control loop
    Two races stand between the pillar camera and its own thread, and both are
    silent rather than loud.
    BlockMap has no lock. observe() appends to _blocks while merging a frame,
    rebinds it at the end of _count_misses, and mutates hits/x/y on a Block in
    place - so a control loop calling confirmed() can iterate a list that is
    being appended to, or read a block whose is_confirmed flips halfway through
    target_lateral_mm(). An RLock now makes one frame land as one atomic change;
    reentrant because summary() calls confirmed().
    NavigationManager.observe_blocks() called get_pose() with the default
    max_age_s, which triggers a fil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
    [block_map.py, navigation_manager.py]
2026-08-22 Run the pillar camera on its own thread
    Detection was the most expensive thing the obstacle round did and the least
    urgent, and it ran inside a control tick. capture_array() blocks until the
    sensor delivers a frame, the solve lands on top of that, and the loop wanted
    to come round every 20ms - so every other tick stretched to several times its
    budget. That is worse than it sounds: _travelled(dt), the steering slew limit
    and report_motion() all integrate dt, so the jitter did not just delay the
    loop, it fed noise into the odometry and the filter's motion model.
    Nothing needs detection to happen inside a tick. The steering reads
    nav.blocks, which persists between frames by design - not the cu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
    [camera_manager.py, task_context.py, test_driving.py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]
2026-08-22 Pace the control loop to a deadline instead of sleeping after the work
    The loop slept a fixed 20ms at the end of every tick, so the real period was
    20ms plus however long the tick ran. With the camera inline that meant it
    alternated roughly 22ms and 60ms.
    dt is not just a schedule in this loop, it is an input.
    PathDrivingTask._travelled(dt) turns it into the distance handed to the
    particle filter's motion model via report_motion(), and _limit_steer_rate
    turns it into how far the servo is allowed to move this tick. A tick that ran
    long therefore arrived late AND told the filter the robot had driven further
    than it had, which is process noise the filter has no way to tell from real
    motion.
    S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
2026-08-22 Stop waiting for the Arduino's acknowledgement inside the control loop
    drive() wrote a command and then blocked on readline() for a reply nothing
    reads. In the good case that is a serial round-trip per steering change inside
    a 20ms tick. In the bad case - one dropped or unterminated reply - it is the
    port's full 0.1s timeout, five ticks of nothing, and it happens on exactly the
    ticks where the steering was moving enough to transmit at all.
    The reply is an acknowledgement, not data, so drive() now writes and returns.
    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
2026-08-22 Add 3D models STL file via upload
    [MotorRack.stl, Pillar.stl, Steering.stl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]
2026-08-22 Read the forward clearance once a tick, and leave the loop a core
    Two leftovers from the same theme.
    _reverse_out() and _choose_speed() each called _front_clearance_mm(), so
    every tick copied the whole 360-slot scan out from under the lidar thread's
    lock twice and re-applied the staleness mask twice. Cheap, but it is also a
    correctness smell: those two are deciding whether to stop and how fast to go,
    and they should be deciding it about the same frame rather than about two
    reads that can disagree. step() now measures it once, up front.
    OpenCV defaults to one worker per core. On a 4-core Pi 5 a round is now
    running three things that matter - the control loop, the lidar scan thread and
    the v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
2026-08-22 Add 3D structures'' STL files and pictures
    [BottomSteeringMount.stl, L_AxleSleeve.stl, L_SteeringArm.stl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]
2026-08-22 Remove 3D structures' STL files and pictures
    [BottomSteeringMount.stl, CamArm.stl, CamArmConnector.stl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]
2026-08-22 Upload 3D structures' STL and PNG files
    [Bottom_SteeringMount.stl, CamArm.stl, CamArmConnector.stl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]
2026-08-22 Update README.md
    Updated descriptions of mechanical parts, sensors, electrical components, and computing components in the README.
2026-08-22 Update mech_README
    Updated the mech README to reflect changes in prototypes, gear specifications, and motor selection. Added detailed descriptions for components and their functions.
2026-08-22 Renamed files
    [BearingMount.stl, Mid_BearingMount.stl, R_BearingMount.stl]
2026-08-22 Add parking bay detection and manoeuvre (detection working, park does not)
    Adds the final round's parking feature as a self-contained unit: bay geometry,
    a lidar detector, and a controller that returns (steer, speed) and never
    touches the motor, so odometry stays in one place.
    classes/parking.py
    BayFinder runs passively on every lap and clusters lidar returns that stick
    out from the outer wall. Verified 10/10 in the bench: all four sections,
    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
2026-08-22 Replace the parking manoeuvre with the four-step parallel park
    Rebuilds ParkingController around the textbook manoeuvre instead of the
    lattice-search shuffle:
    0 APPROACH come off the racing line to stage_depth_mm, slowly and with a
    short lookahead, holding parallel to the wall
    1 stop with the rear axle level with the FAR wall, plus an offset
    2 ARC_IN full lock toward the wall, reversing, until the yaw reaches
    turn_deg
    3 STRAIGHT wheels centred, reversing, until deep enough that the closing
    arc will finish at park_depth_mm
    4 ARC_OUT opposite full lock, still reversing, until square
    Every distance is a tunable, name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
    [parking.py, test_parking.py]
2026-08-22 Update meach_README.md
    Updated the README with images and descriptions of the structural prototypes, detailing changes made in each version.
2026-08-23 Edit models file
    [BearingMount.stl, Bottom_SteeringMount.stl, L&R_AxleSleeve.stl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]
2026-08-23 edit and add models file
    [BearingMount.stl, BearingSystem.stl, Bottom_SteeringMount.stl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]
2026-08-23 Add models' STL files and pictures
    [CamMount.stl, LiDARMount.stl]
2026-08-23 Enhance electrical design documentation with details
    Updated electrical design documentation to include additional details on power management, wiring diagrams, and component specifications.
2026-08-23 Update meach_README.md
    Updated the README to reflect changes in components and descriptions, including the replacement of Raspberry Pi 5 with Battery and Uno R4, and added details about the LiDAR and IMU mount.
2026-08-23 Update mech_README.md
    Updated mechanical choices section and added details about wheel selection and performance analysis.
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2026-08-23 Update README with motor and gearbox information
    Added images and details about motor selection and gearbox development.
2026-08-24 Create detailed BUILD.md for YBR-SUNFLOWER robot
    Added comprehensive build, assembly, and setup instructions for the YBR-SUNFLOWER robot, including parts list, assembly steps, wiring, software setup, and troubleshooting.
2026-08-25 modified: src/Raspberrypi/classes/block_map.py modified: src/Raspberrypi/classes/motor_manager.py modified: src/Raspberrypi/classes/navigation_manager.py modified: src/Raspberrypi/classes/navigator.p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
2026-08-25 Revise electrical documentation for clarity and detail
    Updated the electrical documentation to clarify component roles, improve descriptions, and correct formatting issues. Enhanced explanations for the electrical system's design evolution and sensor placements.
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2026-08-26 Revise BNO055 IMU details and calibration process
    Updated the BNO055 IMU section to clarify its purpose, placement, and calibration method. Revised the calibration and initialization overview for better understanding.
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2026-08-31 Insert robot layout images in README
    Added images of the robot layout to the README.
2026-08-31 Revise mentor title and add prototype images
    Updated mentor title and added images for prototypes and software development.
2026-08-31 Replace the final round's offset profile with a goal-based planner
    The obstacle round used to drive by bending the racing line sideways: each
    pillar produced a lateral offset, the offset was eased in and out with
    Beziers, and pure pursuit followed the bent line. The geometry was careful but
    the model had a hole in it - the offset it asked for was routinely more than
    the corridor could give, so it was clamped, and nothing downstream knew. A
    pass planned at 300mm and a pass clamped to 25mm produced the same confident
    line and the same status output.
    With the shipped config that was not an edge case, it was every pillar:
    clearance_mm=430 needed 535mm of offset out of a corridor that can give 3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
    [dubins.py, goal_planner.py, test_goal_planner.py]
2026-08-31 Update README with soldering images and remove TODO
    Removed TODO placeholder and added images for soldering and wiring work.
2026-08-31 modified: src/Raspberrypi/classes/navigation_manager.py modified: src/Raspberrypi/classes/object_solver.py modified: src/Raspberrypi/classes/parking.py modified: src/Raspberrypi/classes/pure_pursuit.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
2026-09-02 Fix lidar offset
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2026-09-02 Correct image source for encoder wiring
2026-09-02 Update software_README.md
    Removed TODOs related to camera FOV verification, competition values confirmation, real-track performance metrics, and failure log documentation.
